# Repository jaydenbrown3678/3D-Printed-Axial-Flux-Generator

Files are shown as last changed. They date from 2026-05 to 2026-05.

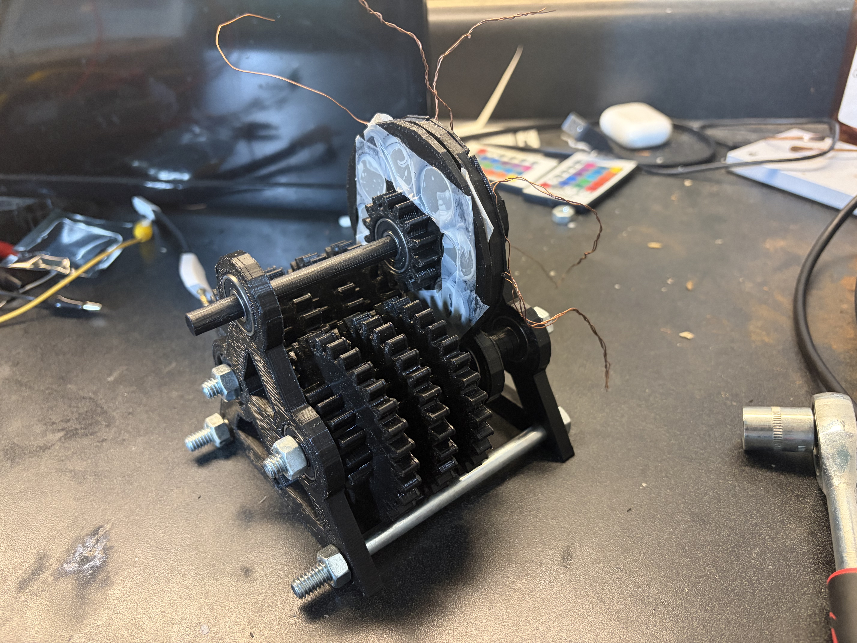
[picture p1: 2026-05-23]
IMG_0718.jpeg

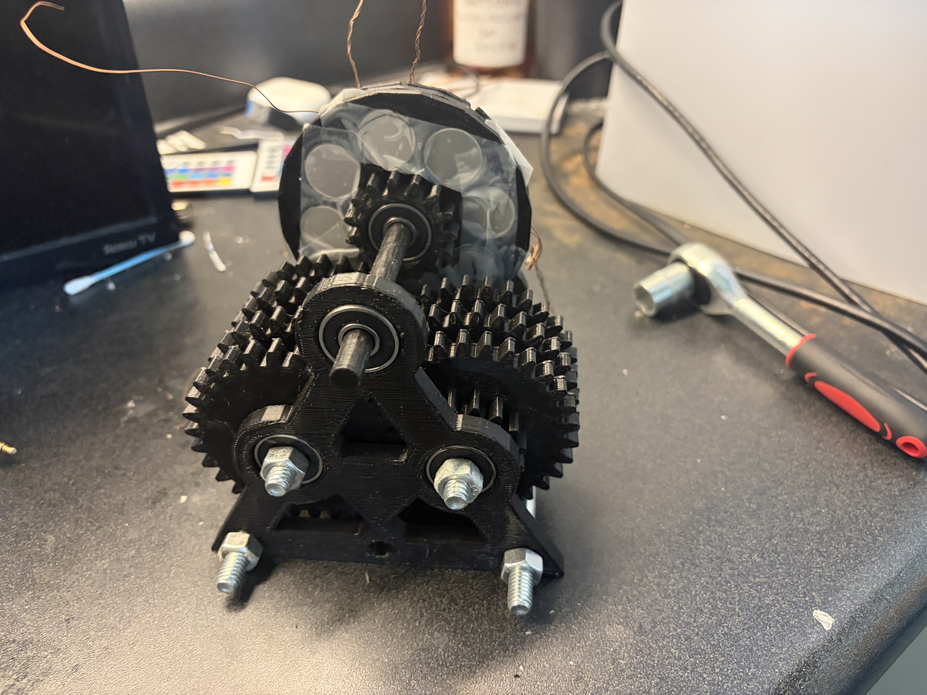
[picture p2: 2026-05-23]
IMG_0717.jpeg

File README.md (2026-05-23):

# 3D-Printed-Axial-Flux-Generator

# 3D-Printed Three-Phase Axial Flux Generator






A hand-cranked, 12V electricity generator built almost entirely from 3D-printed parts and recycled components. This project demonstrates electromagnetic induction principles and is designed to be assembled without a drill press, lathe, or other heavy machinery.

![Generator Image]





---

##  Table of Contents

- [Overview](#overview)
- [Features](#features)
- [How It Works](#how-it-works)
- [Bill of Materials (BOM)](#bill-of-materials-bom)
- [3D Printing Instructions](#3d-printing-instructions)
- [Assembly Guide](#assembly-guide)
- [Wiring Instructions](#wiring-instructions)
- [Testing](#testing)
- [Troubleshooting](#troubleshooting)
- [Performance](#performance)
- [Future Improvements](#future-improvements)
- [License](#license)
- [Acknowledgments](#acknowledgments)

---

##  Overview

This generator converts mechanical energy (from a hand crank, wind turbine, or water wheel) into electrical energy. With a built-in 64:1 gearbox, the rotor spins 64 times for every single turn of the input crank, generating usable voltage even at moderate cranking speeds.

**Why build this?**
- Learn electromagnetic induction hands-on
- Generate electricity from recycled materials
- Understand three-phase power systems
- Power small devices like LEDs or charge phones (with a rectifier)

---

##  Features

| Feature | Specification |
|---|---|
| **Phase type** | 3-phase AC output |
| **Target voltage** | 12V DC (after rectification) |
| **Gear ratio** | 64:1 (integrated) |
| **Magnets** | 8 x N52 neodymium (20x3mm) |
| **Coils** | 6 x ~400 turns of 0.1mm magnet wire |
| **Bearings** | 608zz (salvaged from rollerblades) |
| **Frame** | Fully 3D-printed (PLA/PETG) |
| **Drive method** | Hand crank, wind, or water |

---

##  How It Works

This generator operates on **Faraday's Law of Electromagnetic Induction**:

> A changing magnetic field induces voltage in a conductor.

- **Rotor:** Holds 8 neodymium magnets arranged with alternating polarity (N-S-N-S...)
- **Stator:** Holds 6 copper coils arranged in three opposing pairs
- **Gear train:** 64:1 ratio increases rotor speed relative to crank input
- **Rectifier (external):** Converts 3-phase AC to DC for practical use

When you turn the crank, the gears accelerate the rotor. The spinning magnets create a changing magnetic field across the stationary coils, pushing electrons through the wire and generating electricity.

---

##  Bill of Materials (BOM)

### 3D-Printed Parts (PLA or PETG)

| Part | Quantity | Notes |
|---|---|---|
| End plates (with bearing slots) | 2 | |
| Compound gears | 5 | Each needs 2 bearings |
| Single spur gear | 1 | Press-fit M8 hex nut |
| Rotor body | 1 | Holds 8 magnets |
| Stator body | 1 | Holds 6 coils |
| Coil sockets | 6 | Snaps into stator |
| Coil cores | 6 | Metal preferred (or 3D-printed) |
| Washers/spacers | ~30 | Various thicknesses |

### Standard Hardware

| Component | Specification | Quantity | Source |
|---|---|---|---|
| Aluminum rod | 8mm diameter | 1 | Hardware store |
| Bolts | M8 x 130mm (quarter-threaded) | 5 | Hardware store |
| Hex nuts | M8 | ~15 | Hardware store |
| Neodymium magnets | N52, 20x3mm | 8 | Online (Amazon/eBay) |
| Bearings | 608zz (22mm OD) | 15+ | Salvaged from rollerblades |
| Magnet wire | 0.1mm diameter (enameled copper) | 1 spool | Online or recycled (microwave) |
| Crazy glue/Superglue | | 1 tube | Hardware store |
| 3-Phase bridge rectifier | 10A 1000V | 1 | Amazon/eBay |

### Optional / Testing

| Component | Specification |
|---|---|
| Multimeter | With AC/DC voltage |
| Resistor | 220Ω - 1kΩ |
| LED | Standard 5mm |
| Socket wrench or pliers | For cranking |

---

##  3D Printing Instructions

- **Download the design:** [Tinkercad Link](https://www.tinkercad.com/things/6l8Wafbcfa4)
- **Printer:** Any desktop FDM printer (6.5" x 6.5" build area minimum)
- **Nozzle:** 0.4mm - 0.8mm
- **Layer height:** 0.2mm - 0.5mm
- **Infill:** 20-40%
- **Material:** PLA or PETG (PETG recommended for gears for better durability)

**Estimated print times (0.8mm nozzle, 0.5mm layer height):**

| Part | Time |
|---|---|
| End plate | ~47 minutes |
| Compound gear | ~30 minutes |
| Rotor/Stator | ~1-2 hours each |
| Coil sockets | ~15 minutes each |

### Important Tolerances

- Bearing press-fit: Bearings should require force to insert (use vice or hammer with wood block)
- Magnet slots: Magnets should click firmly into place (no glue required)
- Gear teeth: Ensure no stringing or warping for smooth meshing

---

##  Assembly Guide

### 1. Prepare Bearings and Hardware
Press all bearings into their designated slots. Press an M8 hex nut into the single spur gear.

### 2. Wind the Coils (Most Tedious Step)

For each of the 6 coils:
1. Insert a coil core into a coil socket
2. Leave a 10-15cm wire tail
3. Wind ~400 turns of 0.1mm magnet wire
4. Apply superglue every 50 turns to secure windings
5. Leave another tail and glue the final winding
6. Repeat 5 more times

**Tip:** Use a vice and a washer with tape to guide the wire.

### 3. Connect the Coils (3-Phase Wye Configuration)

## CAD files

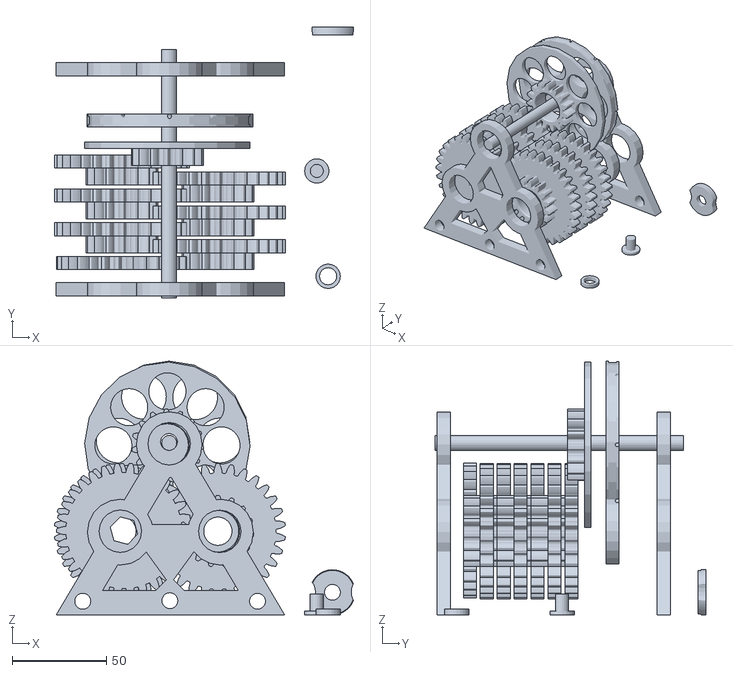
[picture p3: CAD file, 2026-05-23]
Full Build Three-phase axial generator.stl
159.0 x 144.0 x 134.9

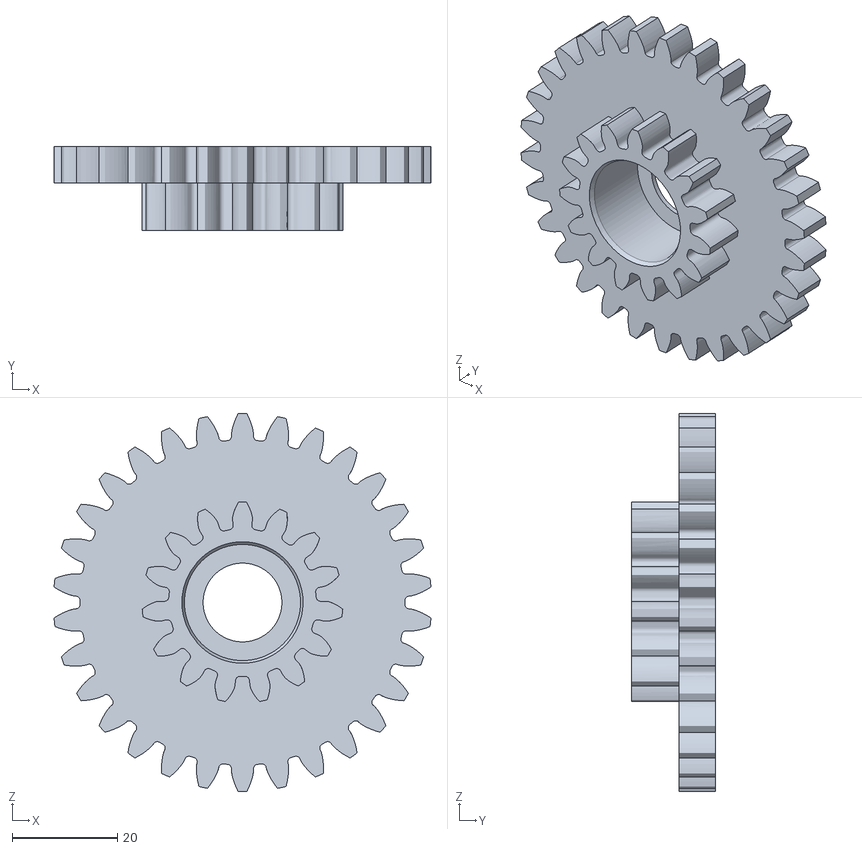
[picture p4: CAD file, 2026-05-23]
Gear4.stl
71.8 x 16.0 x 72.0

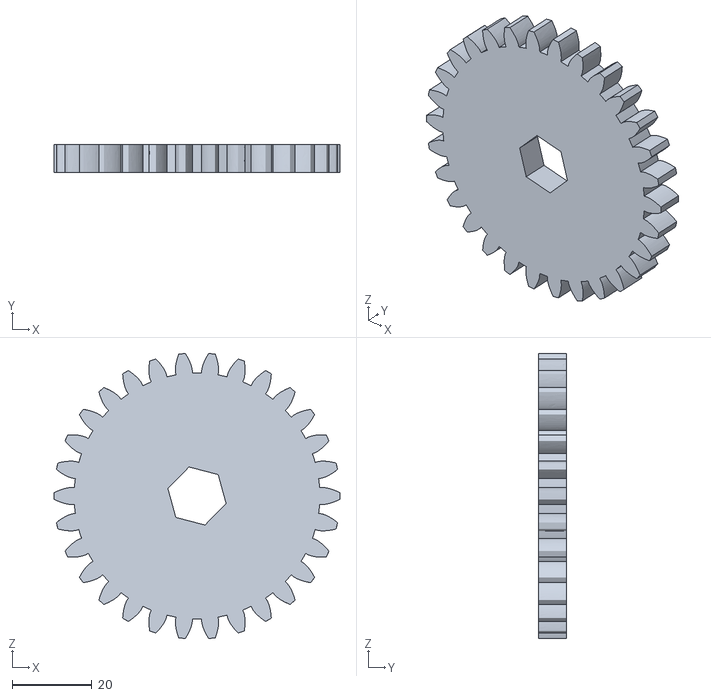
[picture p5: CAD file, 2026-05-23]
Gear6.stl
71.9 x 7.00 x 71.6

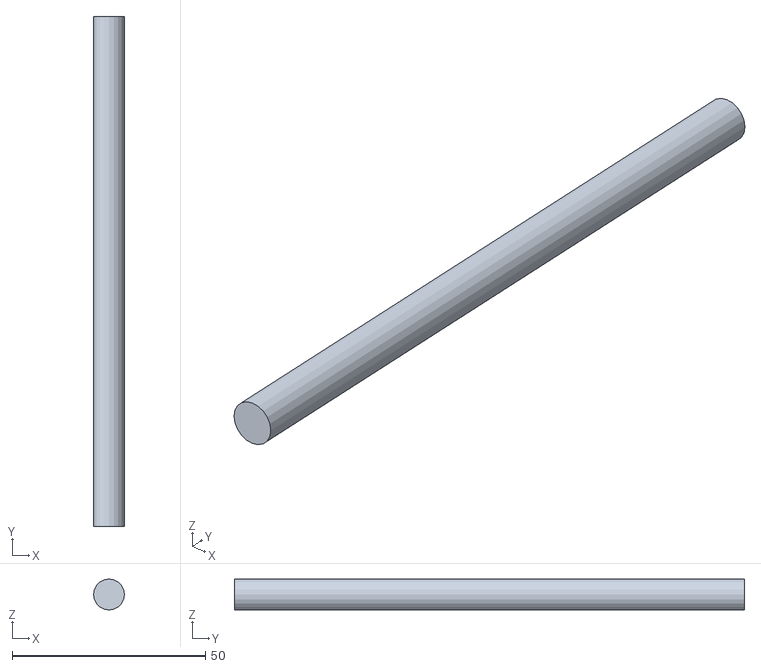
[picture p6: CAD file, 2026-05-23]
Rod_1.1.stl
8.00 x 132.0 x 8.00

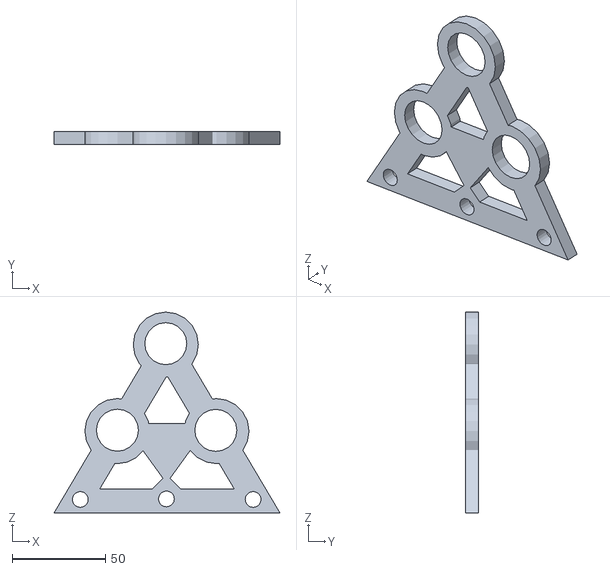
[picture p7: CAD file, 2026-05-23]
Inplate_1.1.stl
121.5 x 7.00 x 108.0

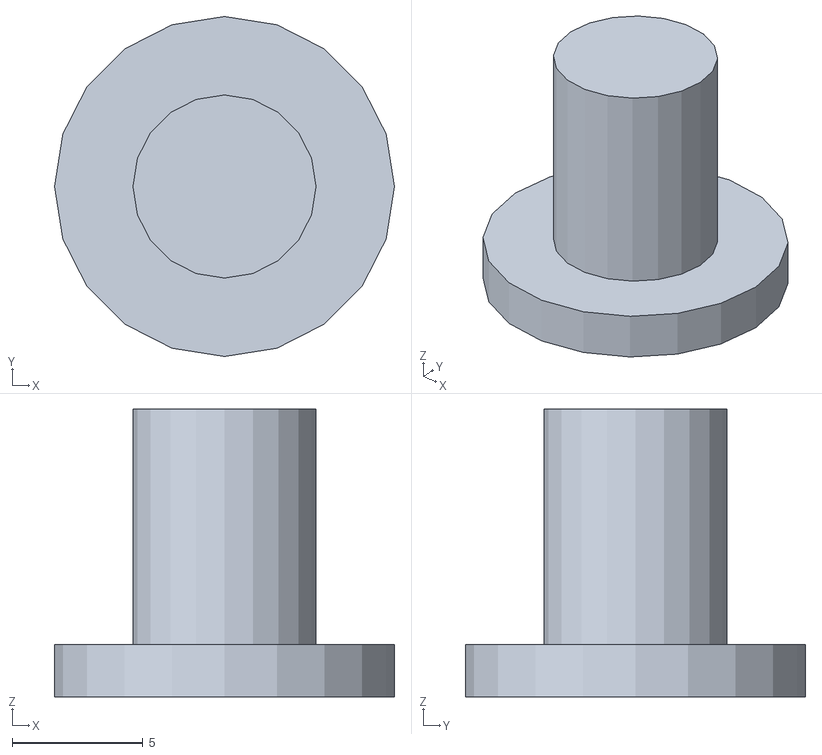
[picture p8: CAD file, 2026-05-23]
Coil Core_1.1.stl
13.0 x 13.0 x 11.0

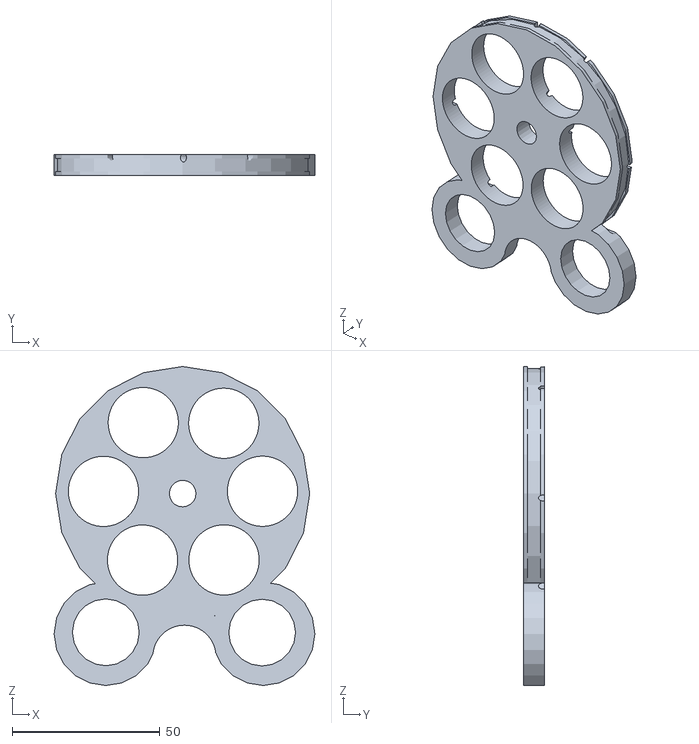
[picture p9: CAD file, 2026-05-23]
Stator_1.1.stl
88.3 x 7.00 x 107.9

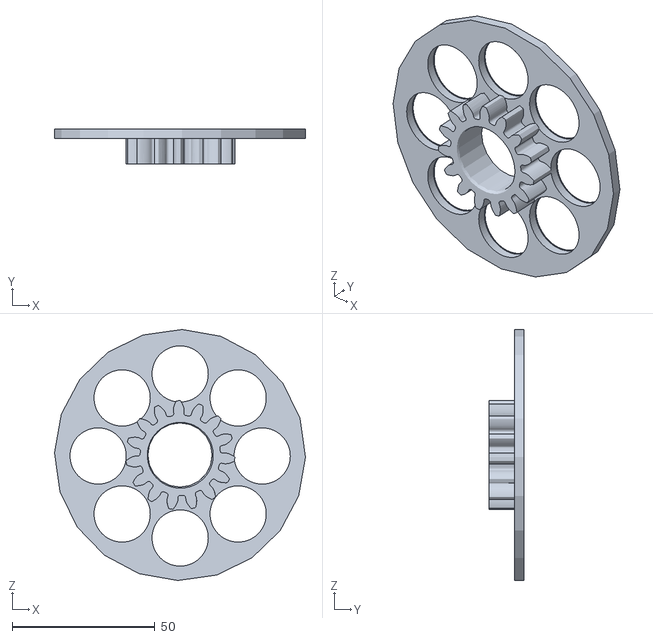
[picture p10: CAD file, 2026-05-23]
Rotor_1.1.stl
88.0 x 12.3 x 88.0

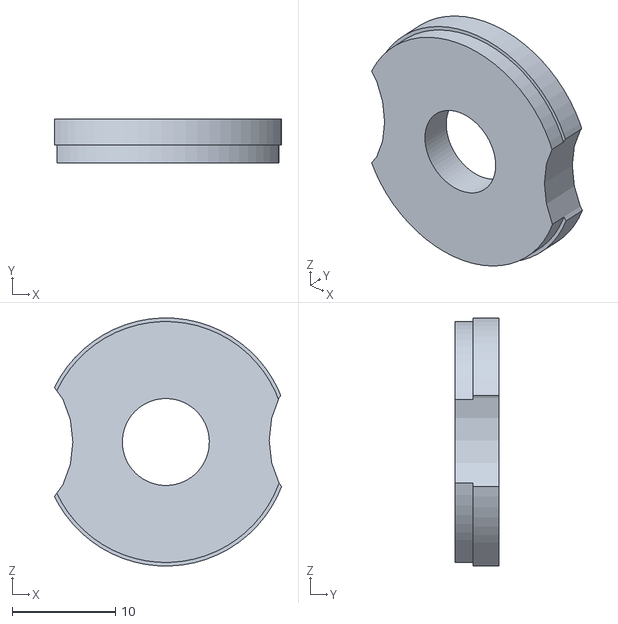
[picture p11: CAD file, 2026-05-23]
Coil_Mount_1.1.stl
22.0 x 4.25 x 24.0

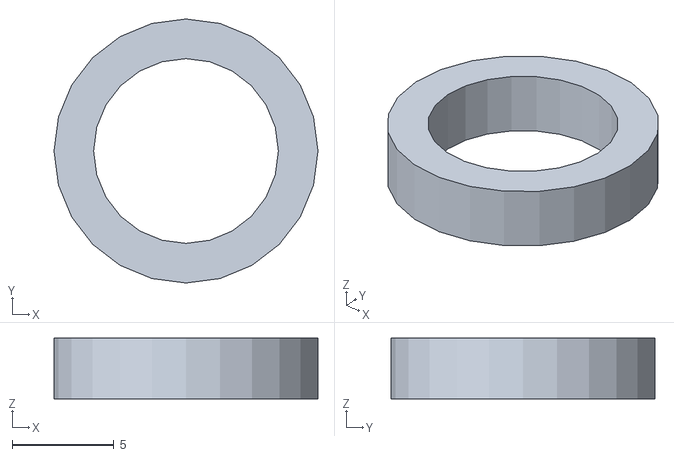
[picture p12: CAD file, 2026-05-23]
Washer_1.2.stl
13.0 x 13.0 x 3.00

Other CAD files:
Gear5.stl
Inplate_1.2.stl
Gear2.stl
Gear1.stl
Gear3.stl

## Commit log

2026-05-23 Added CAD and STL files
    [Coil Core_1.1.stl, Coil_Mount_1.1.stl, Gear1.stl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]
2026-05-23 Full Build of Three-Phase Axial Generator
    [Full Build Three-phase axial generator.stl]

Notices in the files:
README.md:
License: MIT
